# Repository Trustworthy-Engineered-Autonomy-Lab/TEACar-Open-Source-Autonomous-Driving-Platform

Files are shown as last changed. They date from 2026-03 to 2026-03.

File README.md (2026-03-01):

# TEACar
## Introduction
**TEACAR** is a 1/14- to 1/16-scale autonomous racing platform explicitly designed around modularity and hardware abstraction. The platform is intended to support a wide range of experimental configurations. At the mechanical level, the platform adopts a four-layer deck architecture that physically decouples key subsystems, improving mechanical stability while simplifying assembly and component replacement. On the software side, the platform offers a standardized, extensible middleware layer
for sensing, communication, and control via the Robot Operating System (ROS) 2 [10]. The hardware ensures safe and reliable system operation with a dedicated power distribution board, designed to support onboard components with varying voltage requirements.

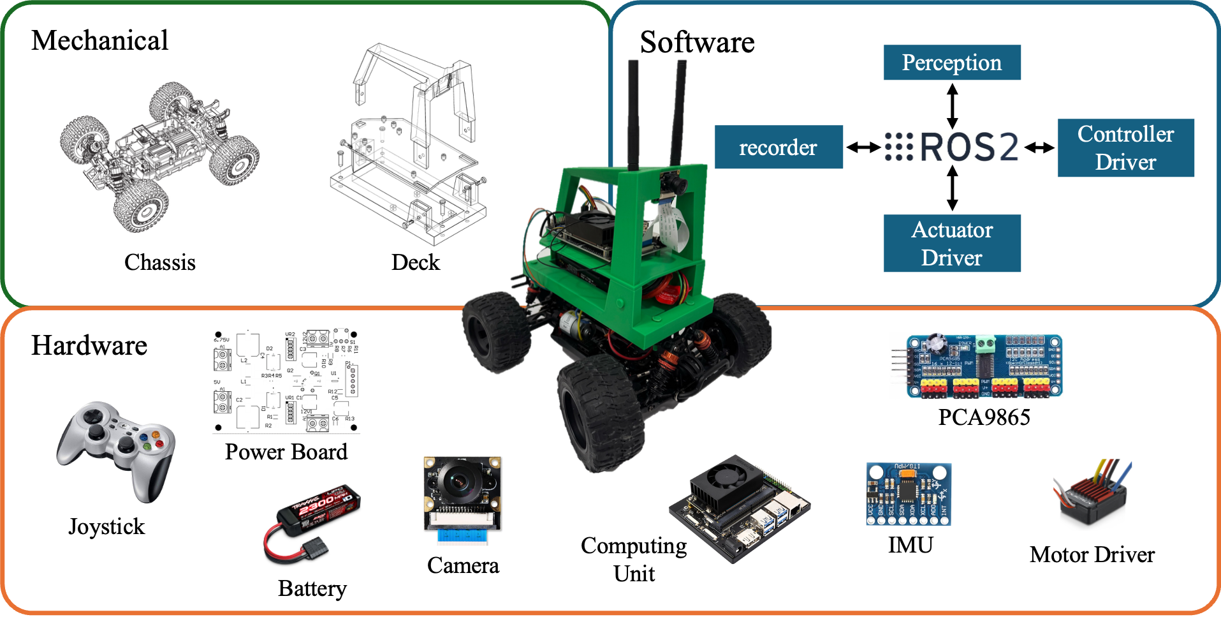
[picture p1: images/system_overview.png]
system overview


### Project layout
```
deck        # STL files for 3D printed parts
powerboard  # Manufacturing files for the power board 
software    # ROS2 package for the TEACar
```

### Build Your Car

#### 1️⃣ Purchase Required Components

- PCA9685 PWM driver board  
- NVIDIA Jetson Orin Development Kit  
- A 1/14- or 1/16-scale RC car chassis  
- Follow the [Power Board Guide](./powerboard/README.md) to order the custom power board and required materials  
- Joystick (recommended: Logitech F710)  
- Camera (optional, for vision-based tasks)

---

#### 2️⃣ Prepare the Mechanical Structure

- Follow the [Deck Guide](./deck/README.md) to print and assemble the deck components  
- Design and 3D print the interface layer between the deck and your selected RC chassis  

---

#### 3️⃣ Assemble the Hardware
- Solder and assemble the power board according to the power board documentation  
- Mount the Jetson board, PCA9685 module, and power board onto the deck using appropriate bolts and standoffs  
- Secure the battery and ensure proper cable management  
- Connect components using Dupont cables or appropriate connectors  
- Double-check wiring and verify correct voltage levels before powering on  

---

#### 4️⃣ Install, Power On, and Configure Software

- Follow the [Software Setup Guide](./software/README.md) to install dependencies and build the project  
- Power on the system  
- Verify that the Jetson boots correctly  
- Confirm that all hardware devices (PWM board, joystick, camera) are detected  
- Configure parameters for your specific chassis and hardware setup  

---

#### 5️⃣ Drive the Car

- Connect the joystick  
- Launch the control stack  
- Test steering and throttle response  
- Begin manual driving

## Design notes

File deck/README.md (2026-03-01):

## Build the deck

### Print parts
You need a 3d printer to print stl files under the `CAM` folder. The required quantity of each printed component is listed in the table below.

| Part Name | File Name | Quantity | Material (Recommended) |
|---|---|---|---|
| Cage | Cage.STL | 1 | PLA |
| Middle Frame | Middle_Frame.STL | 1 | PLA | 
| Bottom Frame | Bottom_Frame.STL | 1 | PLA |
| Split Pin | Split_Pin.STL | 2 | PLA | 
| Long Split Pin | Long_Split_Pin.STL | 1 | PLA |
| Pin | Pin.STL | 4 | PLA | 

### Assemble the deck
Follow the image to assemble the deck
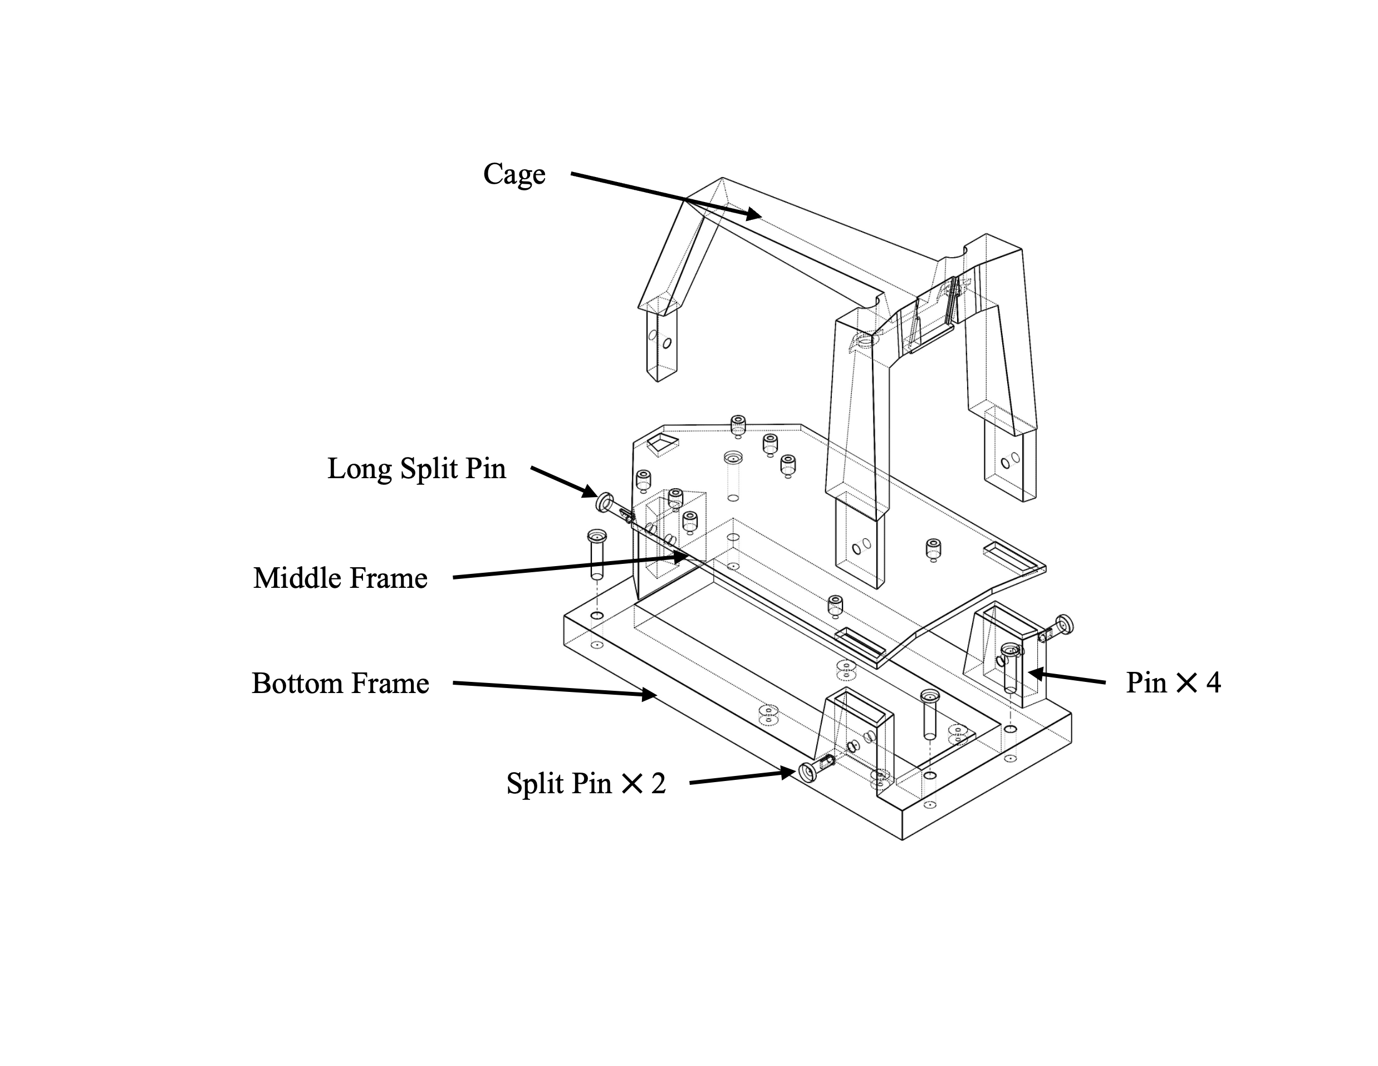
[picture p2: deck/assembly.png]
assembly


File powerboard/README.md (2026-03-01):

## Ordering PCBs
In order to order the most updated PCB from a manufacturer, upload the files under the `CAM` folder to any PCB manufacturing service’s website. Most websites will give various customization options that can typically be left as the default options, though each manufacturer may differ slightly from each other.

## Bill of Materials
The BOM.xlsx includes the description and quantities of the parts used in our design. Some parts that were used were available from the senior design instructors are missing part number information.

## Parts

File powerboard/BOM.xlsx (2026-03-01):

Description | Part Number | Quantity | Unit Price | Price
Buck Converter IC | LM2576T-ADJ | 2 | $1.79 | $3.58
Battery Management IC | LTC4365 | 1 | $5.95 | $5.95
n-channel Power Mosfet | PSMN2R6-30YLC,115 | 2 | $1.81 | $3.62
Shottky Diode | 1N5822 | 2 | $0.28 | $0.56
3-pin Toggle Switch | 2AS1T2A1M6RES | 1 | $1.94 | $1.94
100uF Capacitors | - | 3 | $0.32 | $0.96
1,000uF Capacitors | - | 2 | $0.54 | $1.08
1uF capacitor | - | 1 | $0.10 | $0.10
3.3kOhm Resistors | - | 3 | $0.06 | $0.18
10kOhm Resistors | - | 4 | $0.10 | $0.40
4.7kOhm Resistors | - | 3 | $0.10 | $0.30
1MOhm Resistors | - | 1 | $0.10 | $0.10
22kOhm Resistors | - | 1 | $0.10 | $0.10
100kOhm Resistors | - | 1 | $0.10 | $0.10
100uH Inductor | - | 2 | $3.02 | $6.04
Screw Terminals | - | 4 | $0.40 | $1.60
5-pin Header | - | 1 | $0.24 | $0.24
 |  |  | Total Price | $26.85

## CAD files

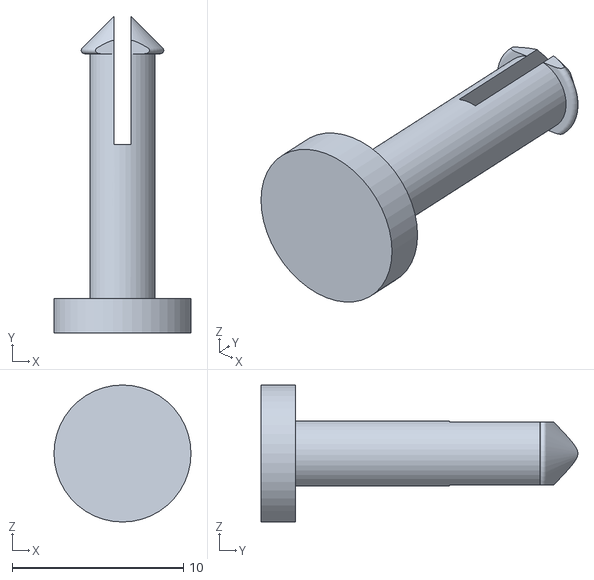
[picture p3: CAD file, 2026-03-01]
deck/CAM/Long_Split_Pin.STL
8.00 x 18.5 x 8.00

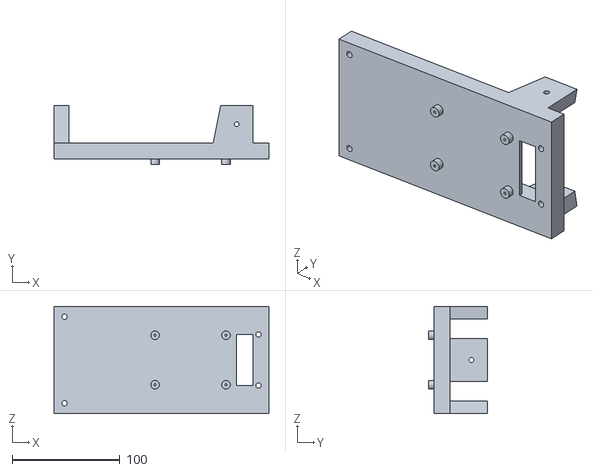
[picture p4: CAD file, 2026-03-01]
deck/CAM/Bottom_Frame.STL
200.0 x 55.0 x 100.0

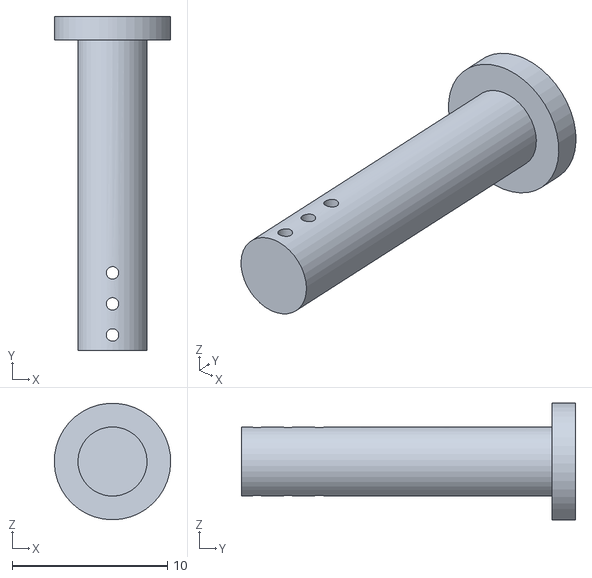
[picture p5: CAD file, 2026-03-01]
deck/CAM/Pin.STL
7.49 x 21.5 x 7.50

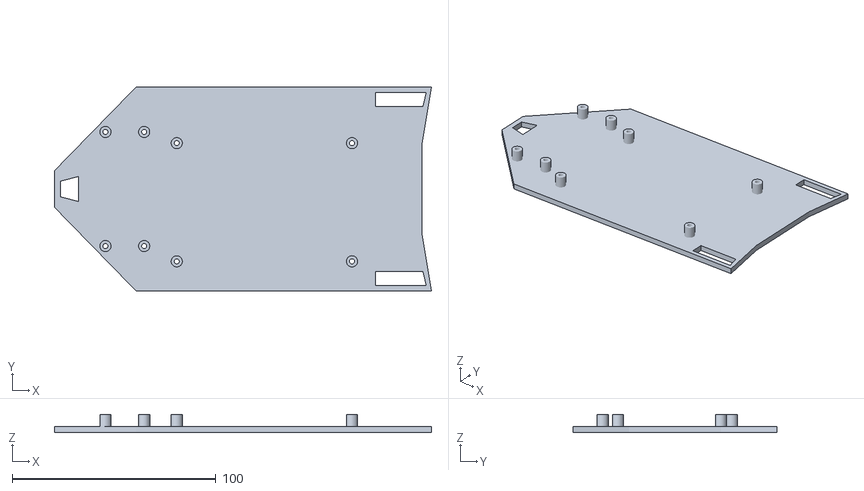
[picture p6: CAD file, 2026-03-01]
deck/CAM/Middle_Frame.STL
185.0 x 100.0 x 9.00

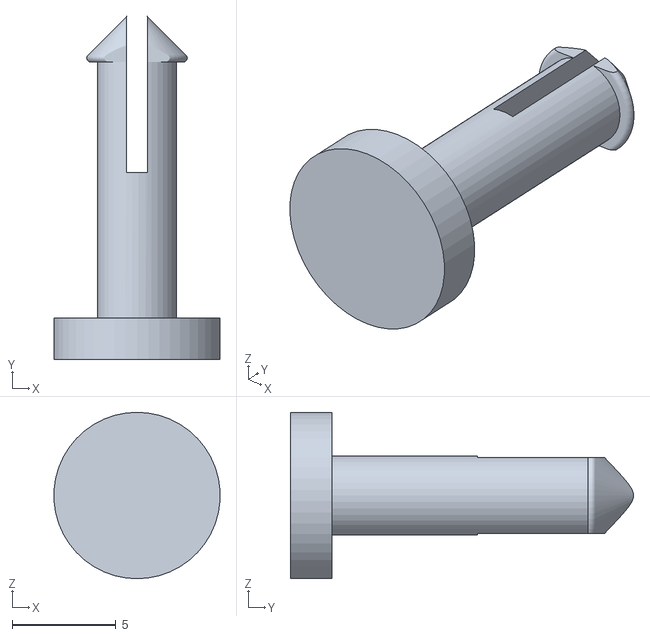
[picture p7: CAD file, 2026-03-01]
deck/CAM/Split_Pin.STL
7.98 x 16.5 x 8.00

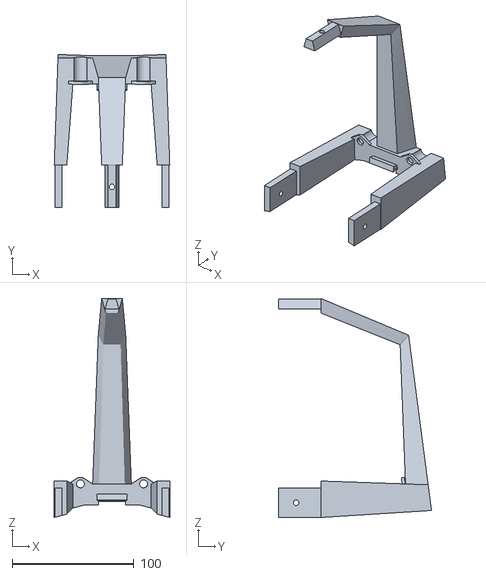
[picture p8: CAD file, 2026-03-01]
deck/CAM/Cage.STL
95.0 x 125.8 x 180.0

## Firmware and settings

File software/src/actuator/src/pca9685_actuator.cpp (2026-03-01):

// pca9685_actuator_node.cpp
#include "actuator.hpp"  // Base class
#include "rclcpp/rclcpp.hpp"
#include <memory>
#include <fcntl.h>
#include <unistd.h>
#include <sys/ioctl.h>
#include <linux/i2c-dev.h>
#include <cmath>

using std::placeholders::_1;

class PCA9685
{
public:
    PCA9685() = default;
    ~PCA9685() { Close(); }

    bool Open(const std::string &device_name, int address = 0x40, int freq = 60)
    {
      fd_ = open(device_name.c_str(), O_RDWR);
      if (fd_ < 0) {
        error_ = "Failed to open I2C device: " + device_name;
        return false;
      }
      if (ioctl(fd_, I2C_SLAVE, address) < 0) {
        error_ = "Failed to get I2C access for: " + device_name;
        return false;
      }
      reset();

      return setPWMFreq(freq);
    }

    void Close()
    {
      if (fd_ >= 0) 
      {
        uint8_t value = 0;
        
        readReg(MODE1, &value);
        writeReg(MODE1, value | 0x10);

        close(fd_);
        fd_ = -1;
      }
    }

    bool setPWMFreq(int freq)
    {
      float prescaleval = 25000000.0 / (4096.0 * freq) - 1.0;
      uint8_t prescale = static_cast<uint8_t>(round(prescaleval));
  
      uint8_t oldmode = 0;
      if (!readReg(MODE1, &oldmode)) return false;
      uint8_t newmode = (oldmode & 0x7F) | 0x10;
      if (!writeReg(MODE1, newmode)) return false;

      if (!writeReg(PRESCALE, prescale)) return false;

      if (!writeReg(MODE1, oldmode)) return false;
      usleep(5000);
      return writeReg(MODE1, oldmode | 0x80);
    }

    bool setPWMChannel(int ch, float duty_cycle)
    {
      uint16_t off = static_cast<uint16_t>(4096 * duty_cycle);
      return writeReg(LED0_ON_L + 4 * ch, 0) &&
             writeReg(LED0_ON_H + 4 * ch, 0) &&
             writeReg(LED0_OFF_L + 4 * ch, off & 0xFF) &&
             writeReg(LED0_OFF_H + 4 * ch, off >> 8);
    }

    std::string getError() const { return error_; }
  
private:
    int fd_ = -1;
    std::string error_;
    static constexpr uint8_t MODE1 = 0x00, PRESCALE = 0xFE;
    static constexpr uint8_t LED0_ON_L = 0x06, LED0_ON_H = 0x07;
    static constexpr uint8_t LED0_OFF_L = 0x08, LED0_OFF_H = 0x09;
    static constexpr uint8_t ALL_LED_OFF_H = 0xFD;

    bool reset()
    {
      uint8_t buf[2] = {0x00, 0x06};
      return write(fd_, buf, 2) == 2;
    }

    bool writeReg(uint8_t reg, uint8_t val)
    {
      uint8_t buf[2] = {reg, val};
      return write(fd_, buf, 2) == 2;
    }
  
    bool readReg(uint8_t reg, uint8_t *val)
    {
      return write(fd_, &reg, 1) == 1 && read(fd_, val, 1) == 1;
    }
};


class PCA9685ActuatorNode : public actuator::Actuator
{
public:
    PCA9685ActuatorNode() : actuator::Actuator()
    {
    this->declare_parameter("bus_device", std::string("/dev/i2c-1"));
    this->declare_parameter("pwm_frequency", 60);
    this->declare_parameter("steer_pwm_channel", 1);
    this->declare_parameter("throttle_pwm_channel", 0);
    this->declare_parameter("steer_min_pw", 1000);
    this->declare_parameter("steer_mid_pw", 1500);
    this->declare_parameter("steer_max_pw", 2000);
    this->declare_parameter("throttle_min_pw", 1000);
    this->declare_parameter("throttle_mid_pw", 1500);
    this->declare_parameter("throttle_max_pw", 2000);

    // Load once at startup
    this->get_parameter("bus_device", bus_device_);
    this->get_parameter("pwm_frequency", pwm_freq_);
    pca_ = std::make_unique<PCA9685>();

    if (!pca_->Open(bus_device_, 0x40, pwm_freq_)) {
      RCLCPP_ERROR(this->get_logger(), "❌ Failed to init PCA9685: %s", pca_->getError().c_str());
    } else {
      RCLCPP_INFO(this->get_logger(), "✅ Successfully initialized PCA9685");
    }
    }


protected:
    void actuate(float throttle, float steer) override
    {
      // RCLCPP_INFO(this->get_logger(), "Received: throttle = %.2f, steer = %.2f", throttle, steer);

        this->get_parameter("steer_pwm_channel", steer_ch_);
        this->get_parameter("throttle_pwm_channel", throttle_ch_);
        this->get_parameter("steer_min_pw", steer_min_);
        this->get_parameter("steer_mid_pw", steer_mid_);
        this->get_parameter("steer_max_pw", steer_max_);
        this->get_parameter("throttle_min_pw", throttle_min_);
        this->get_parameter("throttle_mid_pw", throttle_mid_);
        this->get_parameter("throttle_max_pw", throttle_max_);

        float steer_pw = steer >= 0 ? steer * (steer_max_ - steer_mid_) + steer_mid_
                                    : steer * (steer_mid_ - steer_min_) + steer_mid_;
        float throttle_pw = throttle >= 0 ? throttle * (throttle_max_ - throttle_mid_) + throttle_mid_
                                        : throttle * (throttle_mid_ - throttle_min_) + throttle_mid_;
        float cycle = 1000000.0f / pwm_freq_;

        float steer_duty = steer_pw / cycle;
        float throttle_duty = throttle_pw / cycle;

        RCLCPP_DEBUG(this->get_logger(), "Calculated PWM -> Throttle: %.2f%%, Steer: %.2f%%", throttle_duty * 100, steer_duty * 100);

        if (!pca_->setPWMChannel(throttle_ch_, throttle_duty)) {
        RCLCPP_ERROR(this->get_logger(), "Failed to write throttle PWM: %s", pca_->getError().c_str());
        }
        else
        {
          RCLCPP_DEBUG(this->get_logger(), "✅ Throttle PWM successfully written: duty = %.3f", throttle_duty);
        }

        if (!pca_->setPWMChannel(steer_ch_, steer_duty)) {
        RCLCPP_ERROR(this->get_logger(), "Failed to write steer PWM: %s", pca_->getError().c_str());
        }
        else
        {
          RCLCPP_DEBUG(this->get_logger(), "✅ Steer PWM successfully written: duty = %.3f", steer_duty);
        }
    }

private:
    std::unique_ptr<PCA9685> pca_;
    std::string bus_device_;
    int pwm_freq_ = 60;
    int steer_ch_, throttle_ch_;
    int steer_min_, steer_mid_, steer_max_;
    int throttle_min_, throttle_mid_, throttle_max_;
    

};

int main(int argc, char **argv)
{
  rclcpp::init(argc, argv);
  auto node = std::make_shared<PCA9685ActuatorNode>();
  rclcpp::spin(node);
  rclcpp::shutdown();
  return 0;
}

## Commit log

2026-03-01 add software submodule and power board files
    [BOM.xlsx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]
2026-03-01 add stl files for the deck
    [Bottom_Frame.STL, Cage.STL, Long_Split_Pin.STL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]
